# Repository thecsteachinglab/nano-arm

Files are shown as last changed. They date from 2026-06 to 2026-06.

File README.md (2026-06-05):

# STEM Club - Nano Robot Arm

Nano Robot Arm

## Goal
- A project for school stem clubs that allows students to build and program their own robot arm. 

## Features

- Small, cheap (<£10 unit cost), easy to store, programmable with Python or manual control with joystick
- Easy to fabricate with laser cutter

## Instructions
- 1. Cut the [DXF file](dxf/) using 3mm plywood.
- 2. Assemble and wire using the [Video Instructions](video-instructions/) and [Wiring Instructions](Nano-Robo-Arm-wiring-instructions.pdf)
- 3. Any issues with assembly, [Watch the complete build video](https://drive.google.com/file/d/1T0vYcdThMgW4G9yLXSIMqu09Ss1U54B_/view?usp=drive_link)
- 4. Upload the firmwmare to the arduino: [Arduino file](nano-arm/RoboArm01_v4/) 
> [!NOTE]
> the 'adafruit pwm servo driver library' is required- installation is covered in the full build video )
- 5. Open Python IDLE and use [myapp.py](python/) to program the bot 
> [!NOTE]
The 'COM' number of the connected arduino must match the number set in the python code. The COM number can be found in device manager->COM & LPT Devices->CH40 - see complete build video for further details)

## Resources

- [Bill of Materials](Bill-of-Materials.csv)
- [Video Instructions](video-instructions/) Step by step animated guide for the build
- [Wiring Instructions](Nano-Robo-Arm-wiring-instructions.pdf)
- [Arduino file](RoboArm01_v4/)- upload to the arduino before or after completing the mechanical assembly, this step is best done by a teacher
- [CAD Model](3D-Model/)

## Complete Build Video

[Watch the build video](https://drive.google.com/file/d/1T0vYcdThMgW4G9yLXSIMqu09Ss1U54B_/view?usp=drive_link)

## Servo horns
> [!NOTE]
the SG90 servo horns requires the second and last hole to be drilled with a 2mm bit, this step is best done by a teacher.
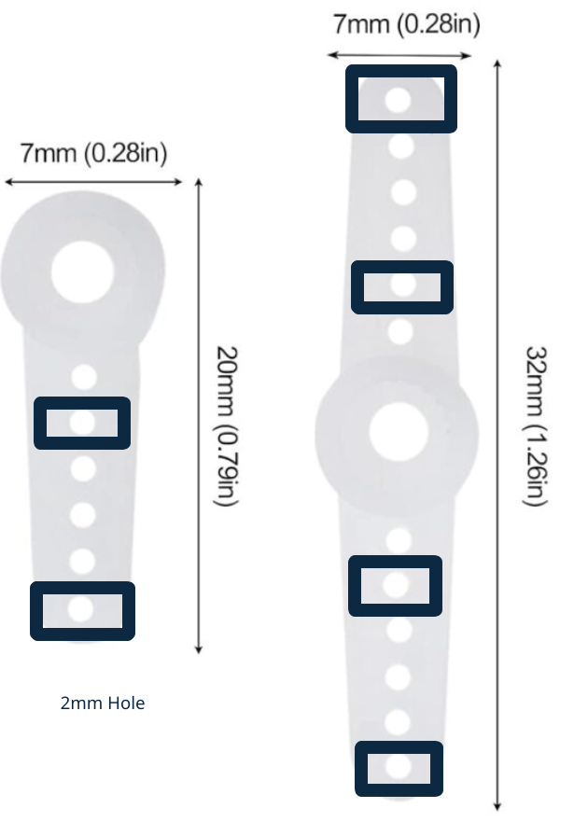
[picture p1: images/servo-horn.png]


### Python programming
checkout www.sparkpy.net for auto-marked coding tasks using 3D graphics

[][cc-by-nc-sa]

This work is licensed under a
[Creative Commons Attribution-NonCommercial-ShareAlike 4.0 International License][cc-by-nc-sa].

[][cc-by-nc-sa]

[cc-by-nc-sa]: http://creativecommons.org/licenses/by-nc-sa/4.0/
[cc-by-nc-sa-image]: https://licensebuttons.net/l/by-nc-sa/4.0/88x31.png
[cc-by-nc-sa-shield]: https://img.shields.io/badge/License-CC%20BY--NC--SA%204.0-lightgrey.svg

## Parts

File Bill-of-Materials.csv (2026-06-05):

ID | Category | Part | Material | Size | Quantity | Description | Fabrication | Estimated Unit Cost | Total Cost | Link
1 | Frame | dxf/nano-arm.dxf | laser plywood | 3mm thick | 1 |  | Laser cutter
2 | Electronics | Arduino Uno R3 |  |  | 1 | MCU | COTS | 2.76 |  | https://www.aliexpress.com/item/1005009463538789.html. https://www.amazon.co.uk/R3-At328PU-Board-Microcontroller-Development-compatible-Environment/dp/B0D8W2QKNJ
3 | Electronics | Servo Shield |  |  | 1 | Servo Controller board | COTS | 3.43 |  | https://www.aliexpress.com/item/1005006882192877.html. https://www.amazon.co.uk/DollaTek-Driver-Module-Channel-Arduino
4 | Electronics | Micro Servo |  |  | 6 | Servo motors | COTS | 1 |  | https://www.amazon.co.uk/Compatible-Projects-Raspberry-Helicopter-Airplane/dp/B0FFHFKQYR
5 | Electronics | Joystick |  |  | 1 | Joystick | COTS | 1.378 |  | https://www.amazon.co.uk/DIGISHUO-Joystick-Controller-JoyStick-Raspberry/dp/B0DT12JLF3
6 | Electronics | Battery Holder |  |  | 1 |  | COTS | 1.7475 |  | https://www.amazon.co.uk/dp/B09XQZ8ZQ2
7 | Electronics | AA Battery |  |  | 4 |  | COTS
9 | Hardware | M3 Bolt |  | 10mm Length | 15 | Joint Frame bolts + arduino+joystick mounting
10 | Hardware | M3 Bolt |  | 25mm Length | 5 | Joint 1 (Base) Bolts + Claw Bolt
 | Hardware | M3 Nut |  |  | 20
 | Hardware | M2 Bolt |  | 8mm Length | 14
 | Hardware | M2 Nut |  |  | 14
 | Electronics | Dupont wire |  |  | 5 | Jumper Wire | COTS | 0.0490833333333333 |  | https://www.amazon.co.uk/DiGiYes-120pcs-Breadboard-Multicolored-Arduino/dp/B0BKZVZC7F
 | Frame | F693ZZ Flanged Bearing |  | ID3 OD8 |  | Claw Bearing | COTS | 0.799 |  | https://www.amazon.co.uk/F693ZZ-Miniature-Bearings-Shielded-Pre-Lubricated/dp/B0CRLH1WT1
Tools
Laser Cutter
Phillips Head Screwdriver
Allen Key for 2mm/3mm Bolt
Hand Drill with 2mm Drill bit
Wire Strippers (optional)
Patience(optional)

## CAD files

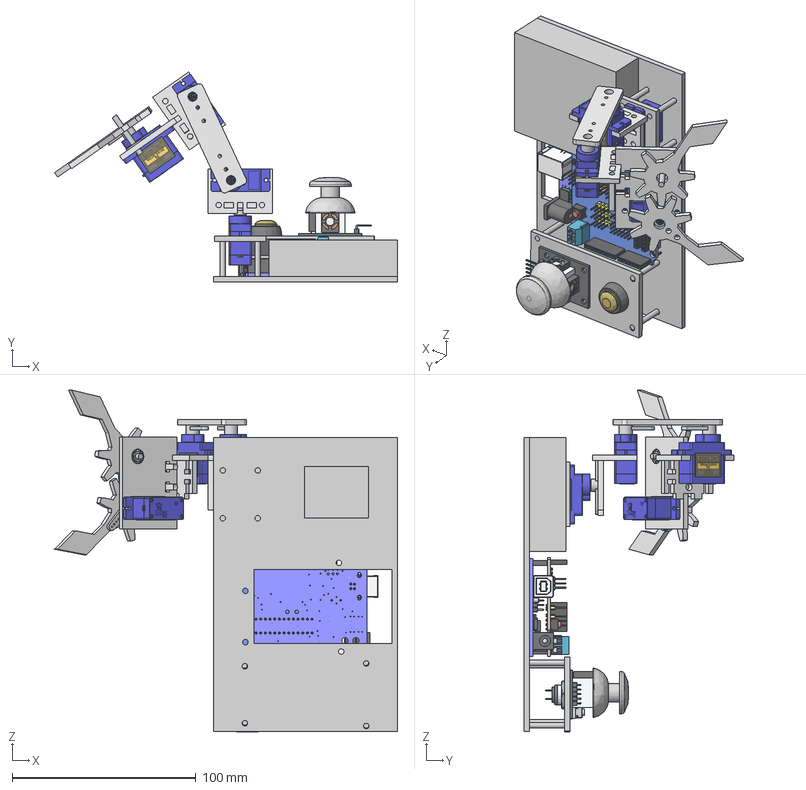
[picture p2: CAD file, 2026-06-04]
3D-Model/nano-arm.step
186.6 x 114.3 x 185.9 mm
DELETE_Arm_Motor_Bottom_Bracket_V4
Arm_Motor_Side_Bracket_V4 x 2
SG90 - Micro Servo 9g - Tower Pro_4 x 4
SG90 - Micro Servo 9g - Tower Pro (3) x 4
micro_servo_arm x 3
Arm_H_Connector_V4
Arm_Motor_Bracket_V4
claw_support_V4
3mm Bearing SKF 623 (RS 285-0790)
claw
tmp_bolt x 9
claw B
SG90 - Micro Servo 9g - Tower Pro (1)
board
potentiometer x 2
tactileswitch-short
joystickhead
base
ArduinoUno
controller
Arduino Sensor Board V1
Button PBS-33^Push Button Switch PBS-33B - yellow
Nut^Push Button Switch PBS-33B - yellow
base motor holder
battery

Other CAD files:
3D-Model/nano-arm.FCStd
dxf/nano-arm.dxf

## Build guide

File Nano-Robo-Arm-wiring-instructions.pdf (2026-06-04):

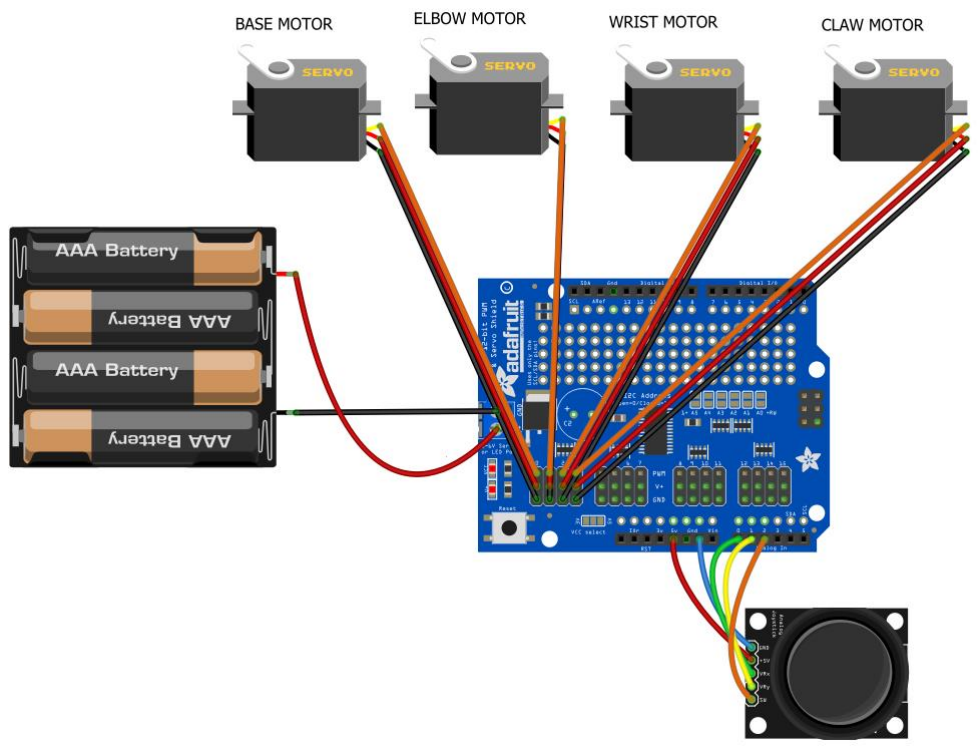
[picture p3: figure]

Robo Arm wiring Instructions v1.0

Completed wiring

Step 1

Disconnect the MCU from USB port

Wiring the joystick to the MCU

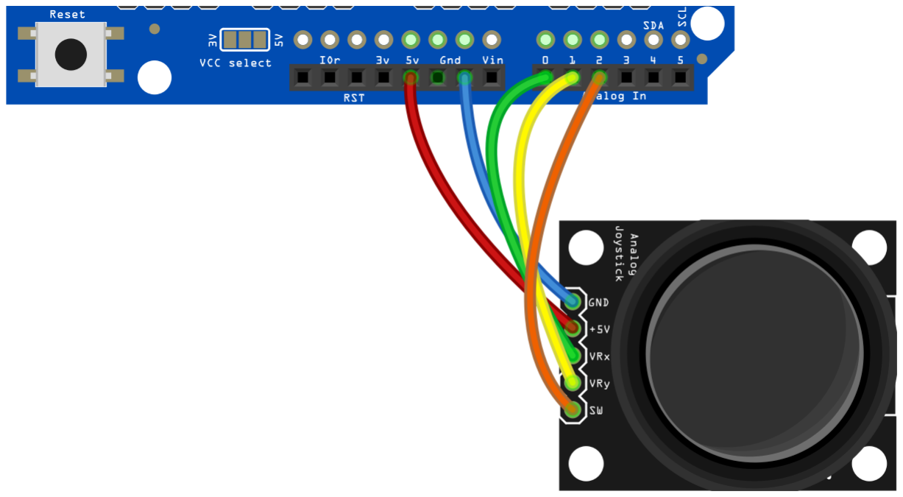
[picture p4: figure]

Joystick Pin | MCU Pin
GND | GND
+5v | 5v
VRx | A0
VRy | A1
SW | A2

Step 2

Wire the motors

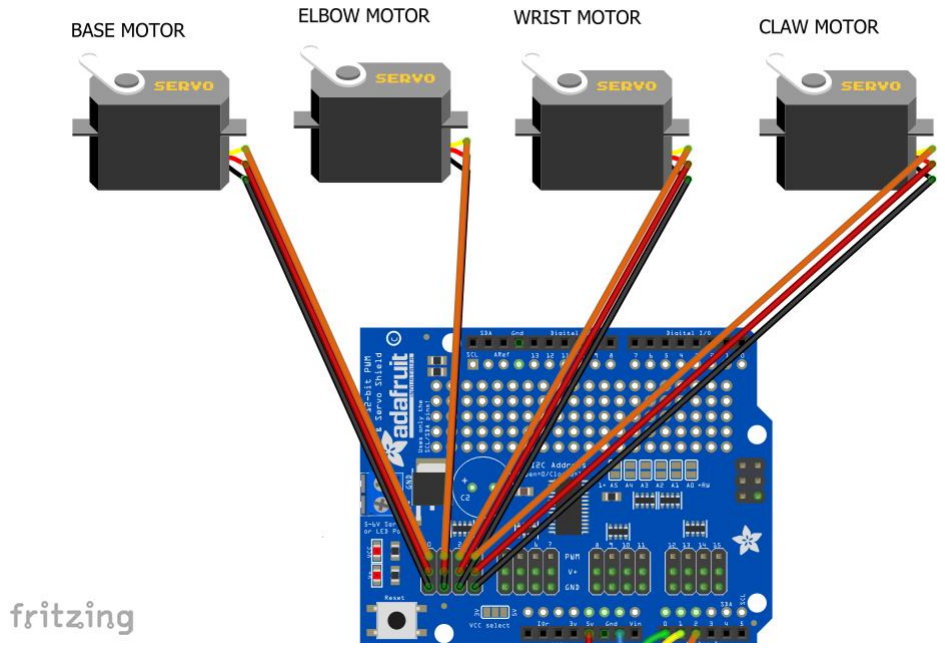
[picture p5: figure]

Claw | Wrist | Elbow | Base

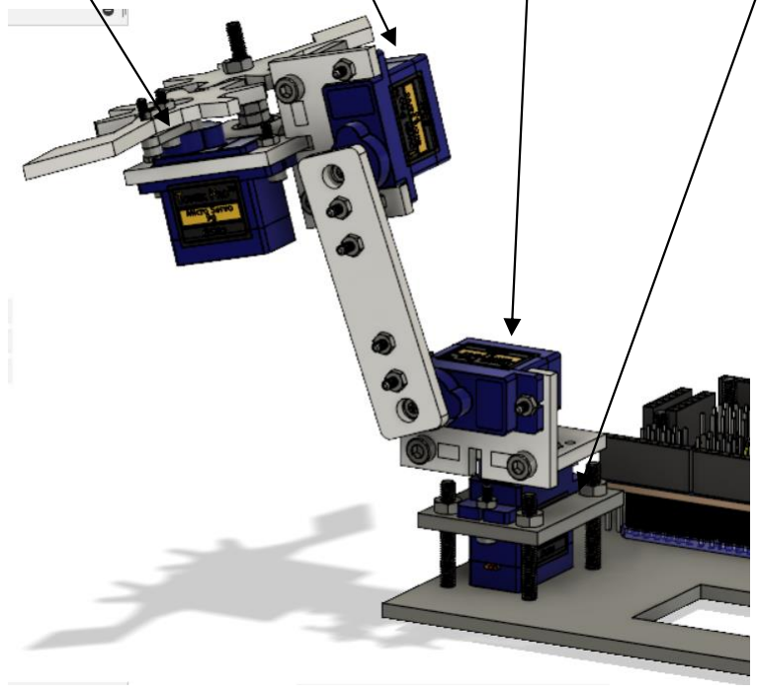
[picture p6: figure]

Step Wire Battery

Warning, do not wire incorrectly!

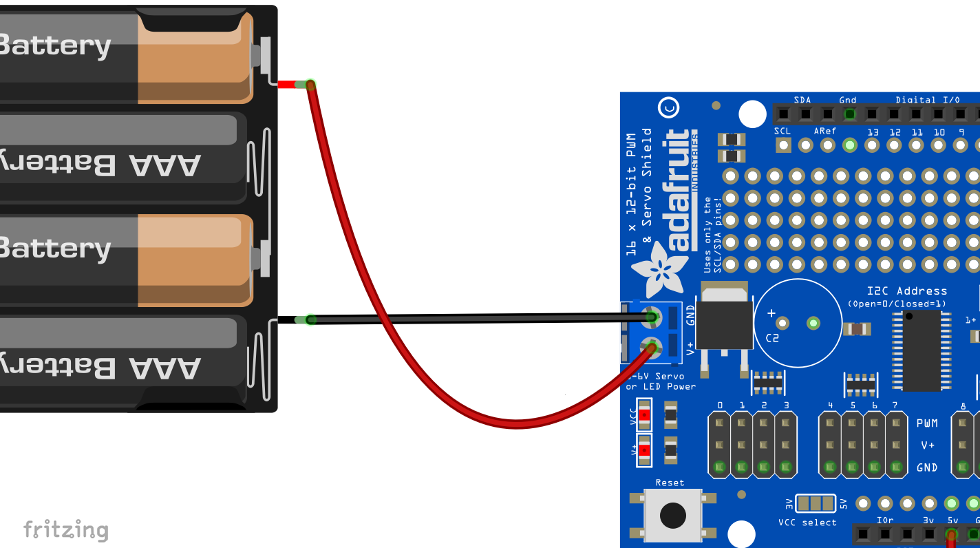
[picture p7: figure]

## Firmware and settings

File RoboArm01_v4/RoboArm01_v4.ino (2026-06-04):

#include <Adafruit_PWMServoDriver.h>
#include <EEPROM.h>

#define VERSION 0.5 //laser version
 
// called this way, it uses the default address 0x40
Adafruit_PWMServoDriver pwm = Adafruit_PWMServoDriver();


// Depending on your servo make, the pulse width min and max may vary, you 
// want these to be as small/large as possible without hitting the hard stop
// for max range. You'll have to twea k them as necessary to match the servos you
// have!
#define SERVOMIN  140 // micro servo this is the 'minimum' pulse length count (out of 4096)
//#define SERVOMAX  600 // micro servo this is the 'maximum' pulse length count (out of 4096)
#define SERVOMAX  500


/* Robo Arm 01 definiions */
#define NUM_SERVOS 4

//#define TWO_BASE_MOTORS 2 /* 3D printed arm has 2 base motors, metal arm has 1 base motor */
#define ONE_BASE_MOTORS 1

#define ASCII_TO_INT 48

#define DEBUG 1  //log messages 

#define SERVO_START_ANGLE 90
uint8_t servo_positions[NUM_SERVOS];
uint8_t curr_servo = 0;
uint8_t gServoSpeed = 20; //the lower the faster
char servo_status[NUM_SERVOS]; //'p'-moving positive 'n' -moving negative 's'-stopped



// Calculate based on max input size expected for one command
#define INPUT_SIZE 128


/* Commands */
#define MOVE_NEGATIVE 'n'
#define MOVE_POSITIVE 'p'
#define MOVE_STOP 's'


/*numbers sent from app. anything from 0 to NUM_SERVOS is to move the servo */
#define APP_CMD_STOP 10
#define APP_CMD_SETSPEED 11
#define APP_CMD_RESET 12
#define APP_CMD_GET_VERSION 14
#define APP_CMD_SAVE_SERVOS 15 //saves the current servos into eeprom so when it loas up it uses these values

/*EEPROM values*/
#define STORED_VALUES 128

//joystick
const int SW_pin = A2; // digital pin connected to switch output
const int X_pin = A0; // analog pin connected to X output
const int Y_pin = A1; // analog pin connected to Y output


byte previous_press = 1; //input held high
byte current_press = 1;

#define JOY_CONTROL_LOW 0 //joystick controls lower half of arm base and low motor
#define JOY_CONTROL_HIGH 2 

byte joy_control = JOY_CONTROL_LOW;

#define CONTROL_MODE_JOY 1
#define CONTROL_MODE_SERIAL 2 //controlled by serial command

byte control_mode = CONTROL_MODE_JOY;//default control mode 

void SetServosSync(short servo_num1,short servo_num2,short degrees, short servo_speed = 0)
{
    short reverse = 0;
    short reverse_degrees = 0;
    short reverse_pos = 0;

    reverse_degrees  = 180 - degrees;
   
    short reverse_pulse = map(reverse_degrees, 0, 180, SERVOMIN, SERVOMAX);
    short pulselength = map(degrees, 0, 180, SERVOMIN, SERVOMAX);
    
    
    short curr_pos = servo_positions[servo_num1];
    reverse_pos = servo_positions[servo_num2];

    short target_pos = degrees;
    short target_delta = degrees -  curr_pos;
  
    target_delta = abs(target_delta);
    
    if(servo_speed == 0)
    {
      pwm.setPWM(servo_num1, 0, pulselength);
      pwm.setPWM(servo_num2, 0, reverse_pulse);

      servo_positions[servo_num1] = degrees;
      servo_positions[servo_num2] = reverse_degrees;
    }
    else
    {
      if(target_pos > curr_pos)
      {
        for(int i=0;i<target_delta;i++)
        {
          pulselength = map(curr_pos+i, 0, 180, SERVOMIN, SERVOMAX);
          reverse_pulse = map(reverse_pos-i, 0, 180, SERVOMIN, SERVOMAX);
          pwm.setPWM(servo_num1, 0, pulselength);
          pwm.setPWM(servo_num2, 0, reverse_pulse);
          delay(servo_speed);
        }
        servo_positions[servo_num1] = degrees;
        servo_positions[servo_num2] = reverse_degrees;
      }
      else if(target_pos < curr_pos)
      {
        for(int i=0;i<target_delta;i++)
        {
          pulselength = map(curr_pos-i, 0, 180, SERVOMIN, SERVOMAX);
          reverse_pulse = map(reverse_pos + i, 0, 180, SERVOMIN, SERVOMAX);
          pwm.setPWM(servo_num1, 0, pulselength);
          pwm.setPWM(servo_num2, 0, reverse_pulse);
          delay(servo_speed);
        }
        servo_positions[servo_num1] = degrees;
        servo_positions[servo_num2] = reverse_degrees;
      }
      
    }
    
}

void SetServoAngle(short servo_num, short degrees, short servo_speed)
{
   
    
  if(servo_num < 1 || servo_num > NUM_SERVOS) //validte servo number
  {
    Serial.print("invalid servo number ");
    Serial.println(servo_num);
    return;
  }

  short reverse = 0;
  short reverse_degrees = 0;
  short servo = 0;

  servo = servo_num - 1; // servos start from index 0
  short curr_pos = servo_positions[servo];
  short pulselength = 0;

  /* move servo 1 & 2 in sync*/
  #ifdef TWO_BASE_MOTORS
  
  if( servo == 1 || servo == 2 )
  {

    SetServosSync(1,2,degrees,gServoSpeed);
    return;
  }
  #endif


  /*
  if(servo_speed == 0)
  {
     servo_positions[servo] = degrees;
     pulselength = map(degrees, 0, 180, SERVOMIN, SERVOMAX);
     pwm.setPWM(servo, 0, pulselength);
     return;
  }
  */
  
  short target_pos = degrees;
  short target_delta = degrees -  curr_pos;
  
  target_delta = abs(target_delta);

  
  
  if(target_pos > curr_pos)
  {
    for(int i=0;i<target_delta;i++)
    {
        pulselength = map(curr_pos+i, 0, 180, SERVOMIN, SERVOMAX);
        pwm.setPWM(servo, 0, pulselength);
        delay(servo_speed);
    }
    servo_positions[servo] = degrees;
  }
  else if(target_pos < curr_pos)
  {
    for(int i=0;i<target_delta;i++)
    {
        pulselength = map(curr_pos-i, 0, 180, SERVOMIN, SERVOMAX);
        pwm.setPWM(servo, 0, pulselength);
        delay(servo_speed);
    }
    servo_positions[servo] = degrees;
  }
  return;
}



void ReadCommand()
{
  // Get next command from Serial (add 1 for final 0)
  
  byte data = Serial.read();
  byte cmd = data;
  byte dir = 0;

  //Serial.print("Data recieved ");
  //Serial.println(data,DEC);

  data = data - ASCII_TO_INT;

  #ifdef DEBUG
  if( !(data >= 1) and (data<=NUM_SERVOS) )
  {
   // Serial.println(data,DEC);
  }
  #endif
  if(cmd == 'm') //switch mode from joystick to serial
  {
    control_mode = CONTROL_MODE_SERIAL;
    return;
  }
  if( (data >= 1) and (data<=NUM_SERVOS) )
  {
    //Serial.print("Servo selected ");
    //Serial.println(data);
    while(!Serial.available()) //wait until another number is sent, this is the direction of the servo
    {
    }
    dir = Serial.read();
    dir = dir - ASCII_TO_INT;
    
    
    
    if( (dir!=1) && (dir!=2)) //error check the dir
    {
      //Serial.print("invalid dir ");
      //Serial.print(dir);
      return;
    }
    else
    {
      //Serial.print("dir is");
      //Serial.println(dir);
      if(dir == 1)
        servo_status[data-1] = MOVE_POSITIVE; //servos index start from 0. App should send starting from index 1
      else
        servo_status[data-1] = MOVE_NEGATIVE;

        curr_servo = data-1;
    }
       
  }
  else if((cmd == APP_CMD_STOP) || (cmd == MOVE_STOP))
  {
    //Serial.println("stopping");
    servo_status[curr_servo] = MOVE_STOP;

  }
    
  else if(cmd == APP_CMD_SETSPEED)
  {
    //Serial.println("Setting speed, waiting for speed");
    while(!Serial.available()) //wait until another number is sent, this is the speed of the servos
    {
    }
    //set the speed;
    gServoSpeed = Serial.read();
    //Serial.print("Received speed ");
    //Serial.println(gServoSpeed);
  }
  else if(cmd == APP_CMD_RESET)
  {
    //Serial.println("Resetting Servos");
    ResetServos();
  }
  else if ( cmd == APP_CMD_GET_VERSION )
  {
    Serial.print("Robo Arm Version: ");
    Serial.print(VERSION);
    #ifdef ONE_BASE_MOTORS
    Serial.println(" Base motors: 1");
    #endif
    #ifdef TWO_BASE_MOTORS
    Serial.println(" Base motors: 2");
    #endif
  }
  else if (cmd == APP_CMD_SAVE_SERVOS)
  {
      Serial.println("Saving Servos"); 
      SaveServos();
  }
  else
  {
    //Serial.println("Invalid command");
  }

}

void SaveServos()
{
 
   short int curr_angle = 0;
    for(int i=0; i < NUM_SERVOS; i++)
    {
      curr_angle = EEPROM.read(i);
      if (curr_angle != servo_positions[i]) //only write if there is a change in the position
      {
     
        EEPROM.write(i,servo_positions[i]);
      }

       
    }

    if(IsServoInfoInMemory() == 0) //if this is the first time we are saving, set the saved values flag
      EEPROM.write(STORED_VALUES,STORED_VALUES);
}

byte IsServoInfoInMemory()
{
  return false;
  //TMP !return ( EEPROM.read(STORED_VALUES) == STORED_VALUES );
}

void SetUpServos(short init_angle)
{
  short int AreServoValuesInMemory = 0;
  short int ServoAngle = 0;

  AreServoValuesInMemory = IsServoInfoInMemory();

 
  if(AreServoValuesInMemory == 1)
  {
 
    for(int i=0; i < NUM_SERVOS; i++)
    {

      #ifdef TWO_BASE_MOTORS
        if ((i==1) || (i==2) ) //dont move the base assume its already at 90 deg
        continue;
      #endif
      ServoAngle = EEPROM.read(i);
      servo_status[i] = MOVE_STOP;

      SetServoAngle(i+1, ServoAngle,gServoSpeed);
    }    
  }

  else
  {
  
    for(int i=0; i < NUM_SERVOS; i++)
    {
      
      servo_positions[i] = init_angle;
      
      servo_status[i] = MOVE_STOP;

      #ifdef TWO_BASE_MOTORS
        if ((i==1) || (i==2) ) //dont move the base assume its already at 90 deg
        continue;
      #endif
    
      SetServoAngle(i+1, init_angle,gServoSpeed);
    }
  }
   
}
void ResetServos()
{

  SetUpServos(SERVO_START_ANGLE);

}
 
            
        

void MoveServos()
{
  short angle = 0;
  char curr_servo_status =' ';
  short servo_step = 1;
  for(int i=0; i < NUM_SERVOS; i++)
  {
   
    curr_servo_status = servo_status[i];
    if(curr_servo_status == MOVE_POSITIVE)
    {
       
        angle = servo_positions[i];
        angle += servo_step;

        if(angle > 180)
          angle = 180;
        SetServoAngle(i+1, angle,gServoSpeed);
        servo_positions[i] = angle;
        delay(gServoSpeed);
    }
    else if (curr_servo_status == MOVE_NEGATIVE )
    {
 
        angle = servo_positions[i];
        angle -= servo_step;
        if(angle <= 0)
          angle = 0;
        SetServoAngle(i+1, angle,gServoSpeed);
        servo_positions[i] = angle;
        delay(gServoSpeed);
    }
    
  }
   
}

void setupJoystick()
{
  pinMode(X_pin, INPUT);
  pinMode(Y_pin, INPUT);
  pinMode(SW_pin, INPUT);
  digitalWrite(SW_pin, HIGH);
}

void switchJoystickControl()
{
  if(joy_control == JOY_CONTROL_LOW)
  {
    servo_status[0] = MOVE_STOP;
    servo_status[1] = MOVE_STOP;
    joy_control = JOY_CONTROL_HIGH;
  }
  else if(joy_control == JOY_CONTROL_HIGH)
  {
    servo_status[2] = MOVE_STOP;
    servo_status[3] = MOVE_STOP;
    joy_control = JOY_CONTROL_LOW;
  }
}

void readJoystick()
{

  const int pos_thresh = 1000; //positive threshold 
  const int neg_thresh = 25;// negative threshold
  
  int xval = analogRead(X_pin);
  int yval = analogRead(Y_pin);

  if(xval > pos_thresh)
  {
    servo_status[joy_control] = MOVE_POSITIVE;
  }
  else if(xval < neg_thresh)
  {
    servo_status[joy_control] = MOVE_NEGATIVE;
  }
  else 
  {
    servo_status[joy_control] = MOVE_STOP;
  }


  if(yval > pos_thresh)
  {
    servo_status[joy_control+1] = MOVE_POSITIVE;
    
  }
  else if(yval < neg_thresh)
  {
    servo_status[joy_control+1] = MOVE_NEGATIVE;
    
  }
  else 
  {
    servo_status[joy_control+1] = MOVE_STOP;
  }
}

bool buttonPress() //jpystick button press
{
  current_press = digitalRead(SW_pin);

  if(current_press == 0 && previous_press == 1)
  {
      previous_press = current_press;
      return true;
  }

  previous_press = current_press;
  
  
  //delay(200);
  return false;
}
 
void setup() {
  Serial.begin(115200); 

  setupJoystick();
   
  pwm.begin();
   
  pwm.setPWMFreq(60);  // Analog servos run at ~60 Hz updates
  
  yield();

  

  //Serial.print("Robo Arm Version ");
  //Serial.println(VERSION);


  int servo = 0;
  int angle_mem = 0;
  int pulselength = 0;
  
  
  for(int i =0; i < NUM_SERVOS; i++)
  {
    if(IsServoInfoInMemory())
    {
       angle_mem = EEPROM.read(i);
       Serial.print(i);
       Serial.print(" ");
       Serial.println(angle_mem);
       pulselength = map(angle_mem, 0, 180, SERVOMIN, SERVOMAX);
       pwm.setPWM(i, 0, pulselength);
       servo_positions[i] = angle_mem;
    }
    else
    {
      pulselength = map(90, 0, 180, SERVOMIN, SERVOMAX);
      pwm.setPWM(i, 0, pulselength);
      servo_positions[i] = 90;
    }
    delay(1000);
  }
  
  
  
  SetUpServos(SERVO_START_ANGLE);
}



void loop() {

  
        if (Serial.available() > 0) {
                
                ReadCommand();        
        }

        if(control_mode == CONTROL_MODE_JOY)
        {
          readJoystick();
        }
        
        if(buttonPress())
        {
          if(control_mode == CONTROL_MODE_JOY)
          {
            switchJoystickControl(); //switches between lower and upper arm control
          }
          else if(control_mode == CONTROL_MODE_SERIAL)//switch from serial to joystick control
          {
             control_mode = CONTROL_MODE_JOY;
          }
          
        }
        
        MoveServos();

}

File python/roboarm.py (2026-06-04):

import serial
import time

DIR_1 = '1'
DIR_2 = '2'

PART_BASE='1'
PART_ELBOW='2'
PART_WRIST='3'
PART_CLAW='4'




class Robo:
    ser=None
    partlookup = {'1':"BASE",'2':"ELBOW",'3':"WRIST",'4':"CLAW"};
    def __init__(self):
        pass
         

    def Initialise(self,com):
        Robo.ser = serial.Serial(com,115200) 

        if(Robo.ser.isOpen() == False):
            Robo.ser.open()

        print("Initialising...")
        time.sleep(5)
        Robo.ser.write(bytes('m','utf-8'))#'m' switches from joystick mode to serial mode
        Robo.ser.flushOutput()
        time.sleep(.1)
        print("Starting...")

    def Send(self,part,direction,seconds):
        if(part!=PART_BASE and part!=PART_ELBOW and part!=PART_WRIST and part!=PART_CLAW ):
            print('Invalid part ', part)
            return
        if(direction !=DIR_1 and direction !=DIR_2):
            print('invalid direction ',direction)
            return

        print(Robo.partlookup[part] + " direction ", direction + " seconds ", seconds)   
    
        Robo.ser.write(bytes(part,'utf-8'))
        Robo.ser.flushOutput()
        time.sleep(.1)
        Robo.ser.write(bytes(direction,'utf-8'))
        Robo.ser.flushOutput()
        time.sleep(.1)
    
        time.sleep(seconds)
        Robo.ser.write(bytes('s','utf-8'))
        Robo.ser.flushOutput()
        time.sleep(.1)


    def Close(self):
        Robo.ser.close()
        print("Closed")

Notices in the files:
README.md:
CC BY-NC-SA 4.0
